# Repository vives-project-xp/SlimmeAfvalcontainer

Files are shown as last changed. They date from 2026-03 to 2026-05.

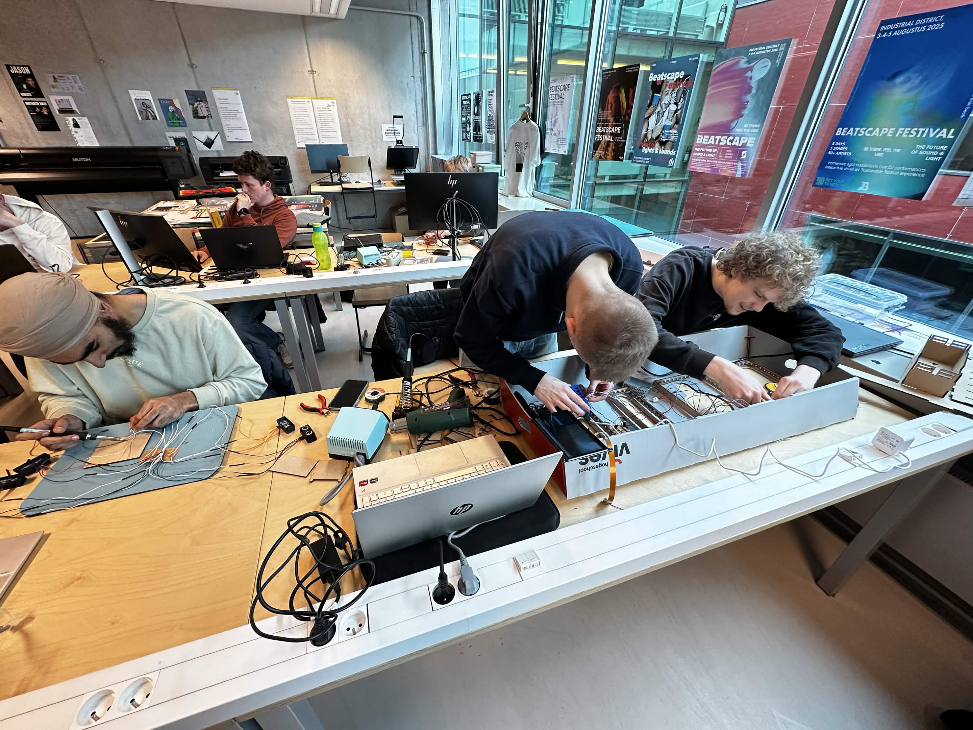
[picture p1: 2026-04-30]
SocialeMedia/Foto's/IMG_4296.jpg

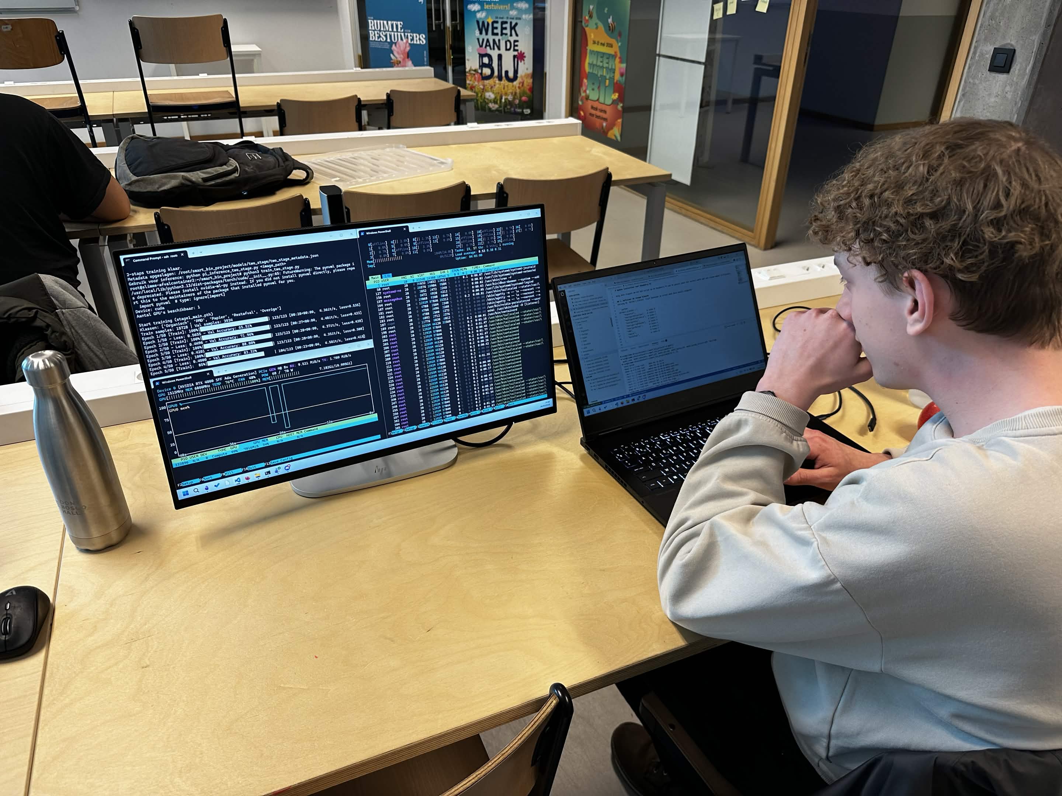
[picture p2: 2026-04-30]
SocialeMedia/Foto's/IMG_4295.jpg

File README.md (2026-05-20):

# Slimme Afvalcontainer

Een intelligente afvalcontainer met camera-gebaseerde objectdetectie, LED-indicatie en ultrasoon sensordetectie. 

## Inhoudstafel

| Onderdeel | Korte uitleg |
|---|---|
| [`Architectuur/`](Architectuur/) | Schema's en architectuurdocumenten van de oplossing. |
| [`Behuizingen/`](Behuizingen/) | Bestanden en ontwerpen voor de fysieke behuizing. |
| [`Code PI/`](Code%20PI/) | Hoofdcode voor de Raspberry Pi, inclusief GUI, LED-sturing en ultrasoon sensoren. |
| [`Datasets/`](Datasets/) | Informatie en links naar de datasets en model-artifacts op Kaggle. |
| [`Documentaties/`](Documentaties/) | Extra documentatie voor de Raspberry Pi en serveromgeving. |
| [`Pi_deploy_target96/`](Pi_deploy_target96/) | Deploy-bestanden voor het target96-model op de Raspberry Pi. |
| [`SocialeMedia/Poster/`](SocialeMedia/Poster/) | Poster- en presentatiemateriaal van het project. |
| [`RaspberryPI5_Pinout/`](RaspberryPI5_Pinout/) | Pinout-informatie voor de Raspberry Pi 5. |
| [`TestCodeC++/`](TestCodeC++/) | Testcode in C++ voor onderdelen van het systeem. |
| [`inference_gui.service`](inference_gui.service) | Systemd-service om de inferentie-GUI automatisch te starten. |
| [`start_garbage_gui.sh`](start_garbage_gui.sh) | Startscript voor de garbage detection GUI. |
| [`test_uart.py`](test_uart.py) | Python-testscript voor UART-communicatie. |

## Projectbeschrijving

Dit project implementeert een slimme afvalcontainer die:

- **Automatisch afvaltype detecteert** via camera en AI-objectdetectie.
- **Visueel aanduidt** welke container gebruikt moet worden met NeoPixel LED's.
- **Controleert of afval gevallen is** met ultrasoon sensoren.
- **Versnelde inferentie** ondersteunt via de Hailo AI Hat+.

## Hardware

| Component | Doel |
|---|---|
| Raspberry Pi 5 | Hoofd verwerkingseenheid |
| Hailo AI Hat+ | Hardware AI-acceleratie (optioneel) |
| Raspberry Pi Camera 3 | Objectdetectie |
| NeoPixel LED-strip | Visuele container-indicatie |
| Ultrasoon sensoren (HC-SR04) | Afvalniveaudetectie |

## GitHub en Kaggle verdeling

Deze repository bevat vooral:

- code
- documentatie
- configuratiebestanden
- het compacte referentie-modelpakket

Voor reproduceerbaarheid gebruiken we daarnaast Kaggle voor de grote bestanden:

- originele foto's: [Smart Bin Original Images](https://www.kaggle.com/datasets/maartenaudenaert/smart-bin-original-images)
- crops voor het finale model: [Smart Bin Classifier Crops](https://www.kaggle.com/datasets/maartenaudenaert/smart-bin-classifier-crops)
- zware modelbestanden en trainingsoutputs: [Smart Bin Model Artifacts](https://www.kaggle.com/datasets/maartenaudenaert/smart-bin-model-artifacts)

Met deze repo samen met die drie Kaggle-links kan het servergedeelte opnieuw worden opgebouwd.

## Gebruikte foto's en datastroom

De foto's zijn verzameld via:

- Google Dataset Search
- Kaggle
- [images.cv](https://images.cv/)

Een deel van de beelden kwam uit Amerikaanse datasets. Daardoor moesten we zelf foto's controleren en hersorteren, vooral voor `PMD`, zodat de sorteerlogica klopt met de regels in Brugge.

De flow voor het finale model is:

1. originele foto's
2. YOLO-detector zoekt het afvalobject
3. daaruit worden crops gemaakt
4. de two-stage classifier traint op die crops

## Serverdocumentatie

Voor de trainings- en exportflow:

- [Documentaties/Server/README.md](Documentaties/Server/README.md)
- [Documentaties/Server/Handleiding/README.md](Documentaties/Server/Handleiding/README.md)

## Links

- [Smart Bin Original Images](https://www.kaggle.com/datasets/maartenaudenaert/smart-bin-original-images)
- [Smart Bin Classifier Crops](https://www.kaggle.com/datasets/maartenaudenaert/smart-bin-classifier-crops)
- [Smart Bin Model Artifacts](https://www.kaggle.com/datasets/maartenaudenaert/smart-bin-model-artifacts)
- [Raspberry Pi Documentatie](https://www.raspberrypi.com/documentation/)
- [Pi Camera 3 Documentatie](https://www.raspberrypi.com/documentation/accessories/camera.html)
- [Hailo RPi5 Voorbeelden](https://github.com/hailo-ai/hailo-rpi5-examples)
- [NeoPixel LED Guide](https://learn.adafruit.com/adafruit-neopixel-uberguide)

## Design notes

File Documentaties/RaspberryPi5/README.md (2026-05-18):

# Smart Bin Raspberry Pi 5 documentatie

Deze map bevat de documentatie om het Raspberry Pi-gedeelte van de slimme
afvalcontainer te begrijpen, opnieuw klaar te zetten en te controleren.

Het gaat hier over de runtime op de Pi: GUI, camera, modelpakket, LED-strips,
ultrasone sensoren en autostart. Training en export van de modellen staan in:

[../Server](../Server/README.md)

## Inhoud

```text
RaspberryPi5/
|-- README.md
|-- Handleiding/
|   |-- README.md
|   |-- 01_pi_en_projectmap/
|   |-- 02_dependencies/
|   |-- 03_modelpakket/
|   |-- 04_gui_en_autostart/
|   |-- 05_leds_en_ultrasoon/
|   `-- 06_controle_en_troubleshooting/
`-- Bestanden/
    |-- README.md
    `-- MANIFEST.txt
```

## Waarvoor dient deze map?

- [Handleiding/](Handleiding/README.md) legt stap voor stap uit hoe de Pi wordt
  klaargezet en hoe de GUI automatisch start.
- [Bestanden/](Bestanden/README.md) beschrijft welke bestanden uit de repo en
  het modelpakket op de Pi nodig zijn.
- [Handleiding/05_leds_en_ultrasoon/hardware/](Handleiding/05_leds_en_ultrasoon/hardware/)
  bevat de detaildocumentatie voor LED-strips, ultrasone sensoren en bedrading.
- [Handleiding/03_modelpakket/referentie/deploy_gids_2_stage.md](Handleiding/03_modelpakket/referentie/deploy_gids_2_stage.md)
  bewaart de oorspronkelijke korte deploygids voor het two-stage model.

## Huidige referentie-installatie op de Pi

De actuele Pi gebruikt deze projectmap:

```text
/home/kobe/SlimmeAfvalcontainer
```

De GUI-service start via:

```text
/etc/systemd/system/garbagedetection-gui.service
```

Die service voert dit script uit:

```text
/home/kobe/SlimmeAfvalcontainer/start_garbage_gui.sh
```

Het huidige modelpakket staat op de Pi onder:

```text
/home/kobe/SlimmeAfvalcontainer/finalmodel
```

Voor compatibiliteit bestaat er ook een symlink:

```text
/home/kobe/SlimmeAfvalcontainer/test11mei_light_crops -> finalmodel
```

Die symlink is belangrijk zolang bestaande startbestanden nog naar
`test11mei_light_crops` verwijzen.

## Snel starten

1. Lees [Handleiding/README.md](Handleiding/README.md).
2. Begin met [01_pi_en_projectmap](Handleiding/01_pi_en_projectmap/README.md).
3. Installeer dependencies via [02_dependencies](Handleiding/02_dependencies/README.md).
4. Plaats of controleer het modelpakket via [03_modelpakket](Handleiding/03_modelpakket/README.md).
5. Zet autostart klaar via [04_gui_en_autostart](Handleiding/04_gui_en_autostart/README.md).
6. Controleer LEDs en ultrasoon via [05_leds_en_ultrasoon](Handleiding/05_leds_en_ultrasoon/README.md).
7. Gebruik [06_controle_en_troubleshooting](Handleiding/06_controle_en_troubleshooting/README.md) bij problemen.

## Belangrijkste runtimebestanden

- `garbagedetection_gui.py`: hoofd-GUI met camera, detectie, classificatie en UI.
- `detector.py`: YOLO ONNX-detectie.
- `classifier.py`: two-stage ONNX-classificatie.
- `led_controller.py`: aansturing van de vier WS2812B LED-strips.
- `ultrasone_controller.py`: monitoring van de vier ultrasone sensoren.
- `start_garbage_gui.sh`: startshellscript voor systemd.
- `garbagedetection-gui.service`: systemd-service voor automatische start.

## Belangrijk gedrag

De Pi gebruikt een detector + classifier-flow:

1. YOLO ONNX zoekt een object in het camerabeeld.
2. De beste crop wordt door de two-stage classifier gestuurd.
3. Stage 1 kiest de hoofdklasse.
4. Bij `Overige` draait Stage 2 voor de subklasse.
5. De GUI vertaalt het resultaat naar een bak of reject-status.
6. LEDs tonen de gekozen bak of een rood reject-signaal.
7. Ultrasone sensoren bevestigen inworp en tonen vulgraad.

## GitHub-opmerking

Niet pushen zonder eerst te controleren welke grote modelbestanden in Git horen.
Voor training en zware artifacts wordt dezelfde verdeling gevolgd als in de
serverdocumentatie:

- GitHub voor code, documentatie, scripts en compacte referentiebestanden
- externe opslag voor zware datasets en grote trainingsoutputs

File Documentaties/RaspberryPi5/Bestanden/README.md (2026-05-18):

# Bestanden Raspberry Pi 5

Deze map beschrijft welke bestanden nodig zijn op de Raspberry Pi. De echte
runtimebestanden staan in de repo vooral onder:

```text
Code PI/
```

en op de Pi onder:

```text
/home/kobe/SlimmeAfvalcontainer/finalmodel
/home/kobe/SlimmeAfvalcontainer/Code PI
```

## Belangrijkste bestanden uit de repo

| Bestand | Doel |
|---|---|
| `Code PI/garbagedetection_gui.py` | Hoofd-GUI |
| `Code PI/led_controller.py` | LED-aansturing |
| `Code PI/ultrasone_controller.py` | Ultrasone sensoren |
| `Code PI/garbagedetection-gui.service` | systemd-servicevoorbeeld |
| `start_garbage_gui.sh` | startshellscript |
| `inference_gui.service` | ouder/alternatief servicebestand |

## Belangrijkste bestanden in het modelpakket

| Bestand | Doel |
|---|---|
| `yolov8_detector.onnx` | YOLO-detector voor objectdetectie |
| `stage1_main.onnx` | Stage 1 hoofdklasse-classifier |
| `stage1_main.onnx.data` | externe data voor Stage 1 ONNX |
| `stage2_overige.onnx` | Stage 2 classifier voor Overige |
| `stage2_overige.onnx.data` | externe data voor Stage 2 ONNX |
| `two_stage_metadata.json` | labels, modelnamen en metadata |
| `detector.py` | ONNX detector wrapper |
| `classifier.py` | ONNX/two-stage classifier wrapper |
| `garbagedetection_gui.py` | runtime GUI in het pakket |

## Opmerking over dubbele LED-controller

De GUI draait uit `finalmodel`, maar de LED-subprocess-code kan
`led_controller.py` uit `Code PI` importeren. Daarom moeten wijzigingen aan
LED-gedrag in beide bestanden gecontroleerd worden:

```text
/home/kobe/SlimmeAfvalcontainer/finalmodel/led_controller.py
/home/kobe/SlimmeAfvalcontainer/Code PI/led_controller.py
```

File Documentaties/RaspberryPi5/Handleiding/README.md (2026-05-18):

# Handleiding Raspberry Pi 5 vanaf nul

Deze handleiding is opgesplitst per onderdeel. Ze is bedoeld voor iemand die de
Raspberry Pi 5-runtime van de slimme afvalcontainer opnieuw wil installeren of
controleren.

Training gebeurt niet op de Pi. De modellen worden serverkant getraind en daarna
als modelpakket naar de Pi gekopieerd.

## Volgorde

1. [Pi en projectmap klaarzetten](01_pi_en_projectmap/README.md)
2. [Dependencies installeren](02_dependencies/README.md)
3. [Modelpakket plaatsen](03_modelpakket/README.md)
4. [GUI en autostart instellen](04_gui_en_autostart/README.md)
5. [LEDs en ultrasoon controleren](05_leds_en_ultrasoon/README.md)
6. [Controle en troubleshooting](06_controle_en_troubleshooting/README.md)

## Detaildocumentatie

- [Two-stage deploygids referentie](03_modelpakket/referentie/deploy_gids_2_stage.md)
- [Hardwaredetails LEDs en ultrasoon](05_leds_en_ultrasoon/hardware/README.md)

## Wat draait er uiteindelijk?

Het doel is een automatisch startende GUI:

```text
garbagedetection-gui.service
`-- start_garbage_gui.sh
    `-- garbagedetection_gui.py --fullscreen
```

De GUI gebruikt dit modelpakket:

```text
finalmodel/
|-- yolov8_detector.onnx
|-- stage1_main.onnx
|-- stage1_main.onnx.data
|-- stage2_overige.onnx
|-- stage2_overige.onnx.data
|-- two_stage_metadata.json
|-- classifier.py
|-- detector.py
|-- led_controller.py
|-- ultrasone_controller.py
`-- garbagedetection_gui.py
```

## Belangrijke uitgangspunten

- De Pi draait de GUI, camera, LEDs en sensoren.
- De Pi traint geen modellen.
- Het modelpakket komt uit de serverflow.
- De huidige productieflow gebruikt `finalmodel`.
- De symlink `test11mei_light_crops -> finalmodel` houdt oude startpaden werkend.

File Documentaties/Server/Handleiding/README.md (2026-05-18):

# Handleiding vanaf nul

Deze handleiding is opgesplitst per onderdeel. Ze is bedoeld voor iemand die nog
geen VM, projectmap of trainingsomgeving heeft en het smart-bin trainingsresultaat
vanaf nul wil kunnen reproduceren.

## Volgorde

1. [VM en projectmap maken](01_vm_en_project/README.md)
2. [Dependencies installeren](02_dependencies/README.md)
3. [Dataset voorbereiden](03_dataset/README.md)
4. [YOLO-detector trainen of klaarzetten](04_detector/README.md)
5. [Cropdataset en two-stage classifier trainen](05_crop_classifier/README.md)
6. [Exporteren en modelpakket maken](06_export_modelpakket/README.md)
7. [Controle, GitHub en grote bestanden](07_controle_en_github/README.md)

## Wat wordt er uiteindelijk gemaakt?

Het doel is een map zoals:

```text
finalmodel/
|-- best.pt
|-- yolov8_detector.onnx
|-- stage1_main.onnx
|-- stage1_main.onnx.data
|-- stage2_overige.onnx
|-- stage2_overige.onnx.data
|-- two_stage_metadata.json
|-- classifier.py
|-- detector.py
|-- main.py
`-- pi_inference_two_stage.py
```

Een referentieversie van dat pakket staat in:

[../Bestanden/Huidig_modelpakket_finalmodel](../Bestanden/Huidig_modelpakket_finalmodel/)

## Belangrijke bijhorende bestanden

- [train_two_stage_crops.py](../Bestanden/Scripts_en_config/train_two_stage_crops.py)
- [export_two_stage_onnx.py](../Bestanden/Scripts_en_config/export_two_stage_onnx.py)
- [train_yolo_l.py](../Bestanden/Scripts_en_config/train_yolo_l.py)
- [train_yolo_until_target.py](../Bestanden/Scripts_en_config/train_yolo_until_target.py)
- [requirements.txt](../Bestanden/Scripts_en_config/requirements.txt)
- [two_stage_metadata.json](../Bestanden/Huidig_modelpakket_finalmodel/two_stage_metadata.json)

## Belangrijk uitgangspunt

Deze documentatie beschrijft serverkant training en export. De installatie op de
Raspberry Pi zelf hoort hier niet bij. De modelbestanden die later naar de Pi
gaan, worden hier wel gemaakt en verzameld.

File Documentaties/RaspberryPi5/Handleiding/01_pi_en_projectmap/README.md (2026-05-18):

# 1. Pi en projectmap klaarzetten

Dit onderdeel begint vanaf een Raspberry Pi 5 waarop Raspberry Pi OS al
geinstalleerd is.

## 1.1 Benodigdheden

Aanbevolen hardware:

```text
Raspberry Pi 5
Raspberry Pi Camera Module
Touchscreen of HDMI-scherm
4 WS2812B LED-strips
4 HC-SR04 ultrasone sensoren
5V voeding voor de LED-strips
netwerktoegang via Wi-Fi of ethernet
```

## 1.2 SSH-toegang

Voor de huidige Pi:

```bash
ssh kobe@10.10.226.229
```

Wachtwoord in de huidige testopstelling:

```text
kobe
```

Gebruik bij een andere Pi het juiste IP-adres.

## 1.3 Projectmap

De huidige projectmap op de Pi is:

```text
/home/kobe/SlimmeAfvalcontainer
```

Controle:

```bash
ls -la /home/kobe/SlimmeAfvalcontainer
```

Je moet onder andere deze onderdelen verwachten:

```text
Code PI/
finalmodel/
start_garbage_gui.sh
```

## 1.4 Modelmap en compatibele symlink

De huidige runtime gebruikt:

```text
/home/kobe/SlimmeAfvalcontainer/finalmodel
```

Omdat oude startbestanden vroeger naar `test11mei_light_crops` verwezen, bestaat
er een symlink:

```bash
cd /home/kobe/SlimmeAfvalcontainer
ln -s finalmodel test11mei_light_crops
```

Controle:

```bash
ls -ld /home/kobe/SlimmeAfvalcontainer/test11mei_light_crops
```

Verwachte output:

```text
test11mei_light_crops -> finalmodel
```

Zonder deze symlink kan de service falen als het startshellscript nog het oude
pad gebruikt.

## 1.5 Camera controleren

Controleer of de camera zichtbaar is:

```bash
rpicam-hello --list-cameras
```

Of test kort:

```bash
rpicam-hello -t 3000
```

Als dit niet werkt, moet eerst de camera-configuratie opgelost worden.

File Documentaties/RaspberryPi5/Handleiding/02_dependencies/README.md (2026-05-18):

# 2. Dependencies installeren

De Pi heeft Python-dependencies nodig voor camera, GUI, ONNX-inference, LEDs en
GPIO.

## 2.1 Systeempackages

Installeer basispackages:

```bash
sudo apt update
sudo apt install -y python3 python3-venv python3-pip python3-tk git
```

Voor camera en GPIO zijn op Raspberry Pi OS meestal al veel packages aanwezig.
Controleer indien nodig:

```bash
sudo apt install -y python3-picamera2 python3-rpi.gpio
```

## 2.2 Virtual environment

In de huidige installatie wordt deze venv gebruikt:

```text
/home/kobe/SlimmeAfvalcontainer/venv_ssp
```

Aanmaken:

```bash
cd /home/kobe/SlimmeAfvalcontainer
python3 -m venv venv_ssp
source venv_ssp/bin/activate
```

## 2.3 Pythonpackages

Installeer minimaal:

```bash
pip install --upgrade pip
pip install numpy pillow opencv-python onnxruntime
pip install adafruit-circuitpython-neopixel rpi_ws281x RPi.GPIO
```

Als `opencv-python` problemen geeft op de Pi, gebruik dan de OS-package:

```bash
sudo apt install -y python3-opencv
```

## 2.4 Rechten voor LEDs

De NeoPixel-library heeft toegang tot GPIO/PWM nodig. Daarom draait de huidige
service als `root`.

Controleer de service:

```bash
systemctl cat garbagedetection-gui.service
```

Verwacht in de huidige setup:

```text
User=root
Group=root
```

## 2.5 ONNX Runtime controleren

Test in de venv:

```bash
source /home/kobe/SlimmeAfvalcontainer/venv_ssp/bin/activate
python -c "import onnxruntime as ort; print(ort.__version__)"
```

Als dit faalt, kan de GUI de modellen niet laden.

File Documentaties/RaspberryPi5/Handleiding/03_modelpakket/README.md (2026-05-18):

# 3. Modelpakket plaatsen

Het modelpakket komt uit de serverdocumentatie. De Pi gebruikt het pakket alleen
voor inference.

De oorspronkelijke korte deploygids staat nu als referentie hier:

[referentie/deploy_gids_2_stage.md](referentie/deploy_gids_2_stage.md)

## 3.1 Huidige locatie

Op de huidige Pi:

```text
/home/kobe/SlimmeAfvalcontainer/finalmodel
```

Controle:

```bash
ls -lah /home/kobe/SlimmeAfvalcontainer/finalmodel
```

## 3.2 Vereiste modelbestanden

Minimaal nodig:

```text
yolov8_detector.onnx
stage1_main.onnx
stage1_main.onnx.data
stage2_overige.onnx
stage2_overige.onnx.data
two_stage_metadata.json
```

Belangrijke Pythonbestanden:

```text
garbagedetection_gui.py
detector.py
classifier.py
led_controller.py
ultrasone_controller.py
```

## 3.3 Inference-flow

De runtime werkt in twee delen:

1. `yolov8_detector.onnx` zoekt objecten in het camerabeeld.
2. De beste crop wordt door de two-stage classifier gestuurd.

Two-stage classifier:

1. Stage 1 kiest een hoofdklasse:

```text
Organisch
PMD
Papier
Restafval
Overige
```

2. Alleen bij `Overige` draait Stage 2:

```text
Batterijen
Elektronica
Glas
Lightbulbs
Metaal
```

3. De GUI combineert dit als bijvoorbeeld:

```text
Overige/Batterijen
```

## 3.4 Metadata

Labels en thresholds mogen niet hardcoded worden als ze uit metadata kunnen
komen. Controleer:

```bash
cat /home/kobe/SlimmeAfvalcontainer/finalmodel/two_stage_metadata.json
```

Belangrijke velden:

```text
input_size
stage1_classes
stage2_overige_classes
stage1_model
stage2_model
main_label_for_stage2
default_fallback
```

## 3.5 Foto-opslag

De huidige runtime mag geen capturefoto's opslaan.

Controleer dat deze map niet terugkomt:

```bash
find /home/kobe/SlimmeAfvalcontainer/finalmodel -maxdepth 1 -type d -name captures
```

Controleer ook dat de GUI geen save-call meer uitvoert:

```bash
grep -n "_save_capture_photo(pil_img)" /home/kobe/SlimmeAfvalcontainer/finalmodel/garbagedetection_gui.py
```

Er hoort geen resultaat terug te komen.

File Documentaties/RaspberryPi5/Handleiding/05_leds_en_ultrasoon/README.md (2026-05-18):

# 5. LEDs en ultrasoon controleren

De Pi gebruikt LED-strips om de gekozen bak te tonen en ultrasone sensoren om
vulgraad en inworp te detecteren.

## 5.1 LED-pinnen

GPIO-mapping volgens de huidige `led_controller.py`:

| Bak | GPIO | Standaardkleur |
|---|---:|---|
| Restafval | GPIO18 | rood |
| Karton/Papier | GPIO13 | blauw |
| Organisch | GPIO12 | groen |
| PMD | GPIO19 | geel |

Detaildocumentatie:

- [hardware/README.md](hardware/README.md)
- [hardware/ledstrip.md](hardware/ledstrip.md)
- [hardware/bedrading.md](hardware/bedrading.md)

## 5.2 LED-gedrag bij classificatie

De GUI vertaalt labels naar een bak of reject-status.

| Modelresultaat | LED-gedrag |
|---|---|
| `Organisch` | Organisch groen, andere bakken rood |
| `PMD` | PMD groen, andere bakken rood |
| `Papier` | Karton/Papier groen, andere bakken rood |
| `Restafval` | Restafval groen, andere bakken rood |
| `Overige` | alle LEDs rood knipperen en rood blijven |
| `Overige/<subklasse>` | alle LEDs rood knipperen en rood blijven |

De subklassen gaan dus bewust naar geen enkele bak:

```text
Overige/Batterijen
Overige/Elektronica
Overige/Glas
Overige/Lightbulbs
Overige/Metaal
```

## 5.3 Waarom rood bij Overige?

`Overige` en alle subklassen betekenen dat de afvalcontainer geen veilige
standaardbak mag kiezen. De LEDs geven daarom een reject-signaal:

```text
reject_blink
```

Dat commando start het knipperen in een subproces, zodat de camera en GUI niet
blijven wachten tot de LED-animatie klaar is.

## 5.4 Oranje flash

Oranje betekent:

```text
inworp bevestigd
```

De ultrasone sensor heeft dan gedetecteerd dat er effectief iets in de gekozen
bak gegooid werd.

Bij `Overige` hoort er normaal geen bak gekozen te worden en dus ook geen
inworp-confirmatie voor een specifieke bak.

## 5.5 Ultrasone pinnen

GPIO-mapping volgens de huidige documentatie:

| Bak | TRIG | ECHO |
|---|---:|---:|
| Restafval | GPIO25 | GPIO26 |
| PMD | GPIO22 | GPIO4 |
| Papier | GPIO23 | GPIO24 |
| Organisch | GPIO17 | GPIO27 |

Detaildocumentatie:

- [hardware/README.md](hardware/README.md)
- [hardware/ultrasone.md](hardware/ultrasone.md)
- [hardware/bedrading.md](hardware/bedrading.md)

## 5.6 Snelle LED-test

Op de Pi:

```bash
cd /home/kobe/SlimmeAfvalcontainer/finalmodel
sudo LED_PROCESS_ISOLATION=0 /home/kobe/SlimmeAfvalcontainer/venv_ssp/bin/python -c "from led_controller import LedController; c=LedController(); print(c.send_command('select_pmd'))"
```

Alles uit:

```bash
sudo LED_PROCESS_ISOLATION=0 /home/kobe/SlimmeAfvalcontainer/venv_ssp/bin/python -c "from led_controller import LedController; c=LedController(); print(c.send_command('off'))"
```

Reject-test:

```bash
sudo LED_PROCESS_ISOLATION=0 /home/kobe/SlimmeAfvalcontainer/venv_ssp/bin/python -c "from led_controller import LedController; c=LedController(); print(c.send_command('reject_blink'))"
```

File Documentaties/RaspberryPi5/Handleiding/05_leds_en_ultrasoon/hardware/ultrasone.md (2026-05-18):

# Ultrasone sensor documentatie

## Overzicht

`ultrasone_controller.py` bewaakt de vullingsgraad van 4 afvalbakken via HC-SR04 ultrasonische sensoren. De metingen lopen continu in een **achtergrond-thread**. Andere modules (bv. `inference_gui.py`) halen de meest recente status op via de `snapshot()` methode.

---

## Hardware

### Sensoren

Elke bak heeft één HC-SR04 sensor met een **TRIG**-pin (trigger) en een **ECHO**-pin. De sensor is diagonaal in de bakhoek geplaatst; de kalibratie-afstand voor een lege bak is daarom langer dan de verticale bakhoogte.

### GPIO pin-mapping (BCM)

| Bak | TRIG pin | ECHO pin |
|---|---|---|
| `rest` | GPIO 25  | GPIO 26  |
| `pmd` | GPIO 22  | GPIO 4 |
| `papier`  | GPIO 16  | GPIO 24  |
| `org` | GPIO 17  | GPIO 27  |

> De GPIO-nummering volgt het BCM-schema (niet de fysieke pin-nummers).

### Aansluitschema per sensor

De HC-SR04 werkt op 5V en geeft een 5V ECHO-signaal terug. De Raspberry Pi GPIO-pinnen zijn echter **3,3V-logica**. Om de GPIO te beschermen wordt een **spanningsdeler** gebruikt op de ECHO-lijn.

**Spanningsdeler (ECHO):**

```
HC-SR04 ECHO (5V)
        │
      [1kΩ]
        │
        ├──── GPIO-pin (Raspberry Pi)
        │
      [2kΩ]
        │
       GND
```

Uitgangsspanning: `5V × 2kΩ / (1kΩ + 2kΩ) ≈ 3,33V` — veilig voor de Raspberry Pi GPIO.

De TRIG-lijn heeft **geen** spanningsdeler nodig: de Pi stuurt 3,3V uit en de HC-SR04 accepteert dit als geldig HIGH-signaal.

**Volledig schema per sensor:**

```
Raspberry Pi GPIO          HC-SR04
  TRIG-pin ─────────────── TRIG
  ECHO-pin ──[1kΩ]──┬───── ECHO
                  [2kΩ]
                    │
                   GND
  GND      ─────────────── GND
  5V       ─────────────── VCC
```

---

## Installatie & vereisten

```bash
pip install RPi.GPIO
```

De module vereist toegang tot GPIO-hardware. Draai het script als root of via `sudo` als GPIO-permissies dit vereisen.

---

## Configuratie

De drempelwaarden zijn klasseconstanten in `UltrasonicMonitor`:

| Constante | Standaard | Beschrijving |
|---|---|---|
| `EMPTY_DISTANCE_CM` | `75.0` | Gekalibreerde afstand (cm) bij een volledig lege bak |
| `THROW_THRESHOLD_CM` | `10.0` | Minimale afstandsdaling (cm) om een inworp te registreren |
| `THROW_DEBOUNCE_S` | `1.5` | Minimale tijd (s) tussen twee opeenvolgende inworp-detecties |
| `THROW_CONFIRM_DELAY_S` | `0.8` | Wachttijd (s) vóór bevestigingsmeting na een mogelijke inworp |
| `THROW_CONFIRM_SAMPLES` | `5` | Aantal samples voor de bevestigingsmeting |
| `THROW_STATUS_HOLD_S` | `2.0` | Hoe lang (s) de status "inworp gedetecteerd" zichtbaar blijft |

---

## Vullingsgraad berekening

De fill-percentage wordt berekend op basis van de gemeten afstand ten opzichte van de lege-bak-referentie:

**Formule:**
```
fill_pct = ((EMPTY_DISTANCE_CM - gemeten_cm) / EMPTY_DISTANCE_CM) * 100
```

Geldige meetafstand: tussen **2 cm** en **400 cm**. Buiten dit bereik geldt de meting als ongeldig (`None`).

Een bak wordt als **vol** beschouwd als:
- gemeten afstand < 5 cm, **of**
- `fill_pct >= 95`

---

## Inworp-detectie

De controller detecteert een inworp via een twee-staps confirmatieprocedure om valse positieven te vermijden:

1. **Drempelcheck**: de afstand daalt meer dan `THROW_THRESHOLD_CM` ten opzichte van de vorige meting.
2. **Debounce**: er zijn minstens `THROW_DEBOUNCE_S` seconden verstreken sinds de laatste inworp.
3. **Bevestiging**: na `THROW_CONFIRM_DELAY_S` seconden wordt opnieuw gemeten (`THROW_CONFIRM_SAMPLES` samples). De daling moet nog steeds aanwezig zijn.
4. **Resultaat**: bij bevestiging wordt `threw_object = True` en wordt de tijdstempel bijgewerkt.

---

## API-referentie

### `UltrasonicMonitor(debug=False, debug_every_cycles=1, sensor_overrides=None)`

Start de achtergrond-thread en initialiseert de GPIO-pinnen.

| Parameter | Type | Beschrijving |
|---|---|---|
| `debug` | `bool` | Zet debug-uitvoer aan in de terminal |
| `debug_every_cycles` | `int` | Druk debug-info elke N meetcycli af (standaard elke cyclus) |
| `sensor_overrides` | `dict[str, dict[str, int] \| None] \| None` | Overschrijf de TRIG/ECHO-pinnen per bak; geef `None` om een bak uit te schakelen |

Bij een mislukte GPIO-initialisatie blijft het object actief maar worden metingen overgeslagen (`enabled = False`).

**Voorbeeld met pin-override:**
```python
monitor = UltrasonicMonitor(
    sensor_overrides={"org": {"trig": 6, "echo": 5}}
)
```

**Voorbeeld met bak uitschakelen:**
```python
monitor = UltrasonicMonitor(
    sensor_overrides={"org": None}
)
```

---

### `snapshot() -> dict[str, dict[str, object]]`

Geeft een momentopname van de huidige sensorstatus terug. Thread-safe.

**Returnstructuur:**
```python
{
    "rest": {
        "fill_pct": int | None,  # Vulgraad 0–100, of None bij geen meting
        "is_full":  bool,        # True als bak vol is
        "threw_object": bool,    # True bij vers gedetecteerde inworp
        "text": str,             # Leesbare statustekst
    },
    # ook "pmd", "papier", "org"
}
```

**Mogelijke statusteksten:**

| Toestand | `text` |
|---|---|
| Geen geldige meting | `"geen meting"` |
| Bak vol | `"VOL (97%)"` |
| Inworp zojuist gedetecteerd | `"inworp gedetecteerd (42%)"` |
| Bak bijna vol (≥ 80 %) | `"bijna vol (83%)"` |
| Normale toestand | `"45%"` |
| Sensor uitgeschakeld of niet aanwezig | `"n.v.t."` |
| Status nog onbekend (bij opstart) | `"onbekend"` |

---

### `close()`

Stopt de achtergrond-thread en maakt de GPIO-resources vrij via `GPIO.cleanup()`. Altijd aanroepen bij afsluiten.

---

## Debug-modus

Zet `debug=True` om per meetcyclus een samenvatting in de terminal te printen:

```
[Ultrasoon DEBUG] rest   trig=25 echo=26 distance=  38.4cm fill= 48 throw=False status=48%
[Ultrasoon DEBUG] pmd    trig=22 echo= 4 distance=  12.1cm fill= 83 throw=False status=bijna vol (83%)
[Ultrasoon DEBUG] papier trig=23 echo=24 distance=   4.2cm fill=100 throw=False status=VOL (100%)
[Ultrasoon DEBUG] org    trig=17 echo=27 distance=  None   fill= -1 throw=False status=geen meting
[Ultrasoon DEBUG] ------------------------------------------------------------------------
```

Met `debug_every_cycles=10` wordt de uitvoer slechts elke 10 cycli geprint.

---

## Gebruik als module

```python
from ultrasone_controller import UltrasonicMonitor

monitor = UltrasonicMonitor()

status = monitor.snapshot()
print(status["rest"]["fill_pct"])      # bv. 48
print(status["pmd"]["threw_object"])   # bv. True
print(status["papier"]["text"])        # bv. "bijna vol (83%)"

monitor.close()
```

---

## Klasse-diagram

```
UltrasonicMonitor
├── __init__(debug, debug_every_cycles, sensor_overrides)
│   ├── GPIO-pinnen instellen (TRIG/ECHO per bak)
│   └── achtergrond-thread starten
│
├── snapshot() -> dict
│   └── thread-safe kopie van _status teruggeven
│
├── Interne methodes
│   ├── _loop()                         – meetlus in achtergrond-thread
│   ├── _measure_distance(cfg)          – enkele HC-SR04 meting (cm of None)
│   ├── _measure_average(cfg, samples)  – gemiddelde van N metingen
│   ├── _calc_fill_pct(distance_cm)     – omrekenen naar vulpercentage
│   ├── _detect_throw_event(...)        – inworp-detectie met bevestiging
│   └── _debug_print(msg)               – conditionele terminal-uitvoer
│
└── close()
```

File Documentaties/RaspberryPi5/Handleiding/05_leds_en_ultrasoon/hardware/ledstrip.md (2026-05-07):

# LED-strip documentatie

## Overzicht

`led_controller.py` stuurt 4 WS2812B LED-strips aan via de GPIO-pinnen van de Raspberry Pi. Elke strip stelt één afvalcategorie voor en krijgt een eigen kleur. De controller biedt een eenvoudige `send_command(cmd)` API die door andere modules (bv. `inference_gui.py`) gebruikt wordt.

---

## Hardware

### Voeding

De strips worden gevoed door een **Meanwell RS-25-5** (5V, 5A). Per strip is een **1000 µF elektrolytische condensator** geplaatst tussen de voeding en de strip om inrushstroom bij het opstarten op te vangen en spanningspieken te dempen. Er zijn dus **4 condensators** in totaal.

**Aansluitschema per strip:**

```
Meanwell RS-25-5
  +5V ──┬─────────────────────────────── +5V ingang LED-strip
       (+)
    condensator
      1000µF
       (−)
        │
  GND ──┴─────────────────────────────── GND ingang LED-strip
```

De condensator hangt **parallel** over de voedingsrail: (+) naar +5V, (−) naar GND. Hij staat dus niet in serie in de stroomweg, maar filtert spanningspieken op de rail.

> Let op de polariteit: de positieve pool naar +5V, de negatieve pool naar GND.

### DIN-lijn weerstand

Op elke **DIN-lijn** (datasignaal van de Raspberry Pi naar de strip) zit een **220 Ω weerstand** in serie. Dit beschermt de eerste LED-driver tegen te hoge instroompieken en vermindert reflecties op de signaalleiding.

```
GPIO-pin ──[ 220 Ω ]──── DIN LED-strip
```

### GPIO pin-mapping (BCM)

| Strip naam | GPIO pin | Aantal LEDs |
|---|---|---|
| `rest` | GPIO 18  | 50 |
| `karton` | GPIO 13  | 37 |
| `organisch`  | GPIO 12  | 50 |
| `pmd` | GPIO 19  | 51 |

> De GPIO-nummering volgt het BCM-schema (niet de fysieke pin-nummers).

### Kleurcodering per afvalcategorie

| Categorie | Kleur | RGB-waarde |
|---|---|---|
| `rest` | Rood | (255, 70, 70) |
| `karton` | Blauw | (70, 140, 255)  |
| `organisch`  | Groen | (0, 255, 0) |
| `pmd` | Geel | (255, 190, 40)  |

### Speciale kleuren

| Toestand | Kleur | RGB-waarde |
|---|---|---|
| Correct (groen) | Groen | (0, 255, 0) |
| Fout (rood) | Rood | (255, 0, 0) |
| Uit | Uit | (0, 0, 0) |

### Overige afvaltypes (speciale kleurenmap)

| Commando | Kleur | RGB-waarde |
|---|---|---|
| `overige` | Lichtgrijs | (160, 160, 160) |
| `overige_batterijen` | Oranje | (255, 120, 40) |
| `overige_elektronica` | Rood-oranje | (255, 60, 60) |
| `overige_glas` | Teal | (40, 190, 170) |
| `overige_lightbulbs` | Geel | (255, 230, 90) |
| `overige_metaal` | Bruin | (150, 120, 95) |

---

## Installatie & vereisten

```bash
pip install adafruit-circuitpython-neopixel rpi_ws281x
```

De neopixel-library vereist toegang tot de GPIO-hardware. Draai het script als root of via `sudo` als GPIO-permissies dit vereisen.

---

## Configuratie via omgevingsvariabelen

Alle instellingen hebben een standaardwaarde maar kunnen overschreven worden via omgevingsvariabelen:

| Variabele | Standaard | Beschrijving |
|---|---|---|
| `LED_BRIGHTNESS` | `0.25` | Helderheid van alle strips (0.0 – 1.0) |
| `LED_MAX_CURRENT_A` | `5.0` | Maximale stroomtoevoer in ampère |
| `LED_CURRENT_HEADROOM`  | `0.85` | Veiligheidsmarge op de max stroom (bijv. 85%) |
| `LED_COUNT_REST` | `50` | Aantal LEDs op de REST-strip |
| `LED_COUNT_KARTON` | `37` | Aantal LEDs op de KARTON-strip |
| `LED_COUNT_ORGANISCH` | `50` | Aantal LEDs op de ORGANISCH-strip |
| `LED_COUNT_PMD` | `51` | Aantal LEDs op de PMD-strip |
| `LED_PROCESS_ISOLATION` | `1` | Subproces-isolatie aan (`1`) of uit (`0`) |

Voorbeeld:
```bash
LED_BRIGHTNESS=0.5 LED_MAX_CURRENT_A=3.0 python led_controller.py
```

---

## Stroombeveiliging (current limiting)

De controller berekent voor elke strip de geschatte stroomopname op basis van de RGB-waarden. Als de totale geschatte stroom de limiet overschrijdt, worden de RGB-waarden proportioneel teruggeschaald.

**Formule:**
```
I_per_led = (R + G + B) / 255 * 20mA
I_totaal  = I_per_led * aantal_leds
```

Als `I_totaal > MAX_CURRENT * HEADROOM`, worden R, G en B vermenigvuldigd met de schaalfactor:
```
schaal = limiet / I_totaal
```

De controller logt dit in de terminal:
```
[LED] Current limit toegepast voor rest: (255, 70, 70) -> (180, 49, 49) (est 6.23A > 4.25A)
```

---

## Subproces-isolatie (process isolation)

Standaard (`LED_PROCESS_ISOLATION=1`) stuurt de controller elk commando door naar een **apart Python-subproces**. Dit beschermt de GUI tegen crashes die veroorzaakt worden door de native neopixel/GPIO-bibliotheek.

- Het kindproces initialiseert zijn eigen `LedController` met `LED_PROCESS_ISOLATION=0`
- Het resultaat wordt via `stdout` teruggegeven aan het hoofdproces
- Timeout per commando: 5 seconden

Zet isolatie uit voor hogere snelheid of bij directe hardware-integratie:
```bash
LED_PROCESS_ISOLATION=0 python led_controller.py
```

---

## API-referentie

### `LedController(led_count_map=None, brightness=0.25)`

Initialiseer de controller. Bij een mislukte GPIO-init blijft de controller actief maar worden LED-commando's genegeerd (de GUI crasht niet).

### `send_command(cmd: str) -> str`

Stuur een commando naar de strips. Geeft een statusstring terug.

#### Ondersteunde commando's

| Commando | Gedrag |
|---|---|
| `pmd` | Enkel de PMD-strip aan in geel, rest uit |
| `rest` | Enkel de REST-strip aan in rood, rest uit |
| `karton` / `papier` | Enkel de KARTON-strip aan in blauw, rest uit (`papier` is alias voor `karton`) |
| `organisch` / `bio` | Enkel de ORGANISCH-strip aan in groen, rest uit (`bio` is alias voor `organisch`) |
| `all` | Alle 4 strips aan in hun eigen kleur |
| `idle` | Zelfde als `all` — alle strips aan in hun eigen kleur |
| `select_<naam>` | Geselecteerde strip groen, de overige drie rood (visuele bevestiging juiste bak) |
| `reject` | Alle strips rood (ongekend of fout afval) |
| `hit` | Herhaal de laatst gekozen categorie (nuttig bij opeenvolgende detecties) |
| `off` | Alle strips uit |
| `reset` | Alle strips uit + reset huidige keuze naar `NONE` |
| `overige` | Alle strips in lichtgrijs |
| `overige_batterijen`  | Alle strips in oranje |
| `overige_elektronica` | Alle strips in rood-oranje |
| `overige_glas` | Alle strips in teal |
| `overige_lightbulbs`  | Alle strips in geel |
| `overige_metaal` | Alle strips in bruin |

#### Returnwaarden

| Return | Betekenis |
|---|---|
| `OK: <CMD>` | Commando succesvol uitgevoerd |
| `UNKNOWN: <cmd>`  | Onbekend commando |
| `ERROR: <cmd>` | Fout tijdens uitvoering |

### `close()`

Zet alle strips uit en geeft GPIO-resources vrij. Altijd aanroepen bij afsluiten.

---

## Gebruik als module

```python
from led_controller import LedController

ctrl = LedController()

ctrl.send_command("pmd")        # PMD-strip aan
ctrl.send_command("select_pmd") # PMD groen, rest rood
ctrl.send_command("all")        # Alle strips aan
ctrl.send_command("off")        # Alles uit

ctrl.close()
```

---

## Standalone testen

```bash
python "Code PI/led_controller.py"
```

Dit doorloopt automatisch de commando's `pmd → rest → karton → organisch → hit → off` met 2 seconden tussentijd.

---

## Klasse-diagram

```
LedController
├── __init__(led_count_map, brightness)
│   ├── proxy_mode: LED-IO via subprocess
│   └── direct: neopixel strips initialiseren
│
├── send_command(cmd) -> str
│   ├── _send_command_via_subprocess(cmd)  [proxy mode]
│   └── directe strip-aanturing            [direct mode]
│
├── Interne methodes
│   ├── _show_bin(bin_name)         – één strip aan, rest uit
│   ├── _show_all_bins()            – alle strips in eigen kleur
│   ├── _show_all_color(rgb)        – alle strips zelfde kleur
│   ├── _show_selection(bin_name)   – groen/rood feedback
│   ├── _set_all(rgb)               – alle strips zelfde kleur (laag niveau)
│   ├── _limit_color_for_strip()    – current limiting
│   └── _estimate_led_current_a()   – stroomschatting
│
└── close()
```

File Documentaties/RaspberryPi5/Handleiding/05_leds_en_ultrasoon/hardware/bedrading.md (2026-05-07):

# Bedrading en softwareconfig WS2812B (4 strips direct op Raspberry Pi)

Deze setup gebruikt geen ESP32 en geen UART meer.
De GUI stuurt de leds direct aan via [Code PI/led_controller.py](Code%20PI/led_controller.py).

## GPIO pinnen voor 4 aparte strips

- REST -> GPIO18 (fysieke pin 12)
- KARTON -> GPIO13 (fysieke pin 33)
- ORGANISCH -> GPIO12 (fysieke pin 32)
- PMD -> GPIO19 (fysieke pin 35)

Deze mapping komt exact overeen met de softwareconfig.

## Aansluiten per strip

Per strip heb je 3 verbindingen:

- 5V voeding -> 5V van de strip
- GND -> GND van de strip
- DATA van gekozen GPIO -> DIN van de strip

## Verplichte extra componenten voor WS2812B

- Plaats een serieweerstand van 330-470 ohm in de datalijn van elke strip.
- Plaats een elco van 1000 uF (minimaal 6.3V) tussen 5V en GND bij de start van de strips.
- Gebruik een externe 5V voeding voor de strips (niet alleen via Pi 5V pin bij veel leds).
- Verbind alle gronden met elkaar: Pi GND + voeding GND + alle strip GND.

## Spanningsniveau data (belangrijk)

De Raspberry Pi gebruikt 3.3V datalogica.
WS2812B op 5V werkt soms direct, maar voor stabiele werking is een level shifter sterk aanbevolen:

- 74AHCT125 of 74HCT14 (3.3V -> 5V) op elke datalijn.

## Voeding snelcheck

Rekenregel: maximaal ongeveer 60 mA per led bij vol wit op 100%.

Formule:

- I_max = aantal_leds * 0.06 A

Voorbeeld bij 191 leds totaal:

- 191 * 0.06 = 11.46 A (theoretisch maximum)

In de praktijk vaak lager door brightness-limiet, maar kies voeding met marge.

## Software vereisten (Pi)

Benodigde Python packages in je venv:

- adafruit-circuitpython-neopixel
- rpi_ws281x

En op OS-niveau:

- Python met GPIO toegang
- start de app bij voorkeur met sudo voor stabiele ws281x toegang

## Runtime configuratie

De led-controller ondersteunt deze omgevingsvariabelen:

- LED_COUNT_REST (standaard: 51)
- LED_COUNT_KARTON (standaard: 38)
- LED_COUNT_ORGANISCH (standaard: 51)
- LED_COUNT_PMD (standaard: 51)
- LED_BRIGHTNESS (standaard: 0.25)
- LED_MAX_CURRENT_A (standaard: 5.0)
- LED_CURRENT_HEADROOM (standaard: 0.85)

Voorbeeld:

- LED_COUNT_REST=51 LED_COUNT_KARTON=38 LED_COUNT_ORGANISCH=51 LED_COUNT_PMD=51 LED_BRIGHTNESS=0.20 LED_MAX_CURRENT_A=5.0 LED_CURRENT_HEADROOM=0.85 sudo -E /pad/naar/python [Code PI/inference_gui.py](Code%20PI/inference_gui.py)

Stroomlimiter in software:

- De controller schat stroom op basis van RGB-waarde en aantal leds van de actieve strip.
- Als de geschatte stroom boven de limiet komt, schaalt de software de RGB-waarde automatisch omlaag.
- Effectieve limiet = LED_MAX_CURRENT_A * LED_CURRENT_HEADROOM.

Huidige fysieke setup:

- REST: 51 leds
- KARTON: 38 leds
- ORGANISCH: 51 leds
- PMD: 51 leds

## Commando mapping vanuit GUI

De GUI stuurt commando's naar de controller:

- organisch -> ORGANISCH strip aan
- pmd -> PMD strip aan
- karton -> KARTON strip aan
- rest -> REST strip aan
- papier -> alias van karton
- bio -> alias van organisch
- off -> alle strips uit
- reset -> alle strips uit en keuze reset

Bij een nieuw commando gaat eerst alles uit, daarna alleen de gekozen strip aan.

## HC-SR04 ultrasonische sensors (4x)

Onderstaande pinout komt overeen met de originele `Ultrasone_controller.py`:

- Sensor 1 (Restafval): TRIG -> GPIO25 (pin 22), ECHO -> GPIO26 (pin 37)
- Sensor 2 (PMD): TRIG -> GPIO22 (pin 15), ECHO -> GPIO4 (pin 7)
- Sensor 3 (Papier): TRIG -> GPIO23 (pin 16), ECHO -> GPIO24 (pin 18)
- Sensor 4 (Glas): TRIG -> GPIO17 (pin 11), ECHO -> GPIO27 (pin 13)

Power voor alle HC-SR04:
- VCC -> 5V (pin 2 of 4)
- GND -> GND (bijv. pin 6, 9, 14, ...)

Belangrijk: ECHO is 5V output. Gebruik altijd een niveauadapter of een weerstandendeler naar 3.3V voor elke ECHO-lijn voordat je het op Pi GPIO input aansluit.

TRIG kan direct vanaf Pi 3.3V output (HC-SR04 erkent dit als hoog genoeg).

### Ultrasonische timing in Python

1. Zet TRIG output laag (2 ms)
2. Zet TRIG ~10 µs hoog
3. Zet TRIG laag
4. Meet hoelang ECHO hoog blijft
5. Afstand (cm) = (duration_microsec / 58)

### Cross-talk voorkomen

- Trigger sensoren één voor één (niet tegelijk), met kleine pauze tussen de metingen.
- Zorg dat je aansturing in software sequentieel gebeurt (sensor 1 -> 2 -> 3 -> 4) en niet parallel, anders kun je echo's verwisselen.

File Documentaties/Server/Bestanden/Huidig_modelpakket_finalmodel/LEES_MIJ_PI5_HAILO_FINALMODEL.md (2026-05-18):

# Test11mei Light Crops: Pi 5 + Hailo HAT pakket

Deze map is bedoeld als klaarzet-map voor de Raspberry Pi 5 met Hailo HAT.

Status:
- dit mapje is bedoeld voor de lichte detectorvariant voor Pi 5 + Hailo HAT
- de two-stage classifierbestanden zitten er al in
- die classifier is nu de crop-gebaseerde two-stage variant uit `models/two_stage_crops`
- de lichte detectorbestanden zitten er ook al in

Wat er nu al in zit:
- `classifier.py`
- `detector.py`
- `hailo_two_stage_main.py`
- `main.py`
- `pi_inference_two_stage.py`
- `stage1_main.onnx`
- `stage1_main.onnx.data`
- `stage2_overige.onnx`
- `stage2_overige.onnx.data`
- `two_stage_metadata.json`

Wat er nog ontbreekt voor Hailo:
- `yolov8_detector.hef`

## Verwachte detectorrun
Runmap:

```bash
/root/smart_bin_project/runs/yolo_light/garbage_detector_pi_light
```

## Stap 1: Controleer deze map
Deze bestanden zouden hier nu aanwezig moeten zijn:
- `best.pt`
- `yolov8_detector.onnx`
- `stage1_main.onnx`
- `stage2_overige.onnx`
- `two_stage_metadata.json`
- `hailo_two_stage_main.py`

## Stap 2: Detector opnieuw exporteren indien nodig
Als je later een nieuwere lichte detectorrun wilt inladen, voer je op de server uit:

```bash
cd /root/smart_bin_project/finalmodel
bash vul_detector_na_training.sh
```

Dat script doet:
- `best.pt` kopieren naar deze map
- `best.pt` exporteren naar ONNX
- de ONNX detector hernoemen naar `yolov8_detector.onnx`

Je kunt ook een andere runmap opgeven:

Standaard haalt dat script de detector uit:

```bash
/root/smart_bin_project/runs/yolo_light/garbage_detector_pi_light
```

## Stap 3: Kopieer deze map naar de Pi 5
Bijvoorbeeld:

```bash
scp -r /root/smart_bin_project/finalmodel pi@<IP_VAN_PI>:/home/pi/
```

## Stap 4: Detector klaarmaken voor Hailo
De Hailo runtime in `hailo_two_stage_main.py` verwacht een bestand met deze naam:

```bash
yolov8_detector.hef
```

Gebruik dus jullie normale Hailo compile-flow om van `best.pt` of `yolov8_detector.onnx` een `.hef` te maken en zet dat bestand in deze map met exact die naam.

Belangrijk:
- `main.py` gebruikt `yolov8_detector.onnx` voor CPU/ONNX-testen
- `hailo_two_stage_main.py` gebruikt `yolov8_detector.hef` voor de Hailo HAT

## Stap 5: Starten op de Pi
Voor Hailo HAT:

```bash
cd ~/finalmodel
python3 hailo_two_stage_main.py
```

Voor ONNX/CPU test:

```bash
cd ~/finalmodel
python3 main.py
```

## Stap 6: Snelle visuele controle
Na training kun je hier evaluatiebestanden verwachten in `evaluatie/`.

## Opmerking
De two-stage classifier in deze map is nu de crop-gebaseerde variant uit `models/two_stage_crops`:
- `stage1_main` validatie-accuracy: `89.46%`
- `stage2_overige` validatie-accuracy: `92.03%`

De detector kan later nog vervangen worden door een nieuwere `best.pt`/`yolov8_detector.onnx`/`.hef` zonder dat je de classifierbestanden opnieuw hoeft te maken.

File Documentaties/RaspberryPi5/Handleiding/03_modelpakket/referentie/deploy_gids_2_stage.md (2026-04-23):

# Raspberry Pi 5 Deploy Gids (2-Stage Model)

Deze gids start **na training**.  
Training is al klaar; we focussen alleen op wat nodig is om inference op de Pi 5 te laten werken.

modellen staan in: 
/home/kobe/SlimmeAfvalcontainer/Code PI/AI

`/home/pi/smart_bin/models/two_stage/`

Benodigd op de Pi:

- `stage1_main.onnx`
- `stage1_main.onnx.data`
- `stage2_overige.onnx`
- `stage2_overige.onnx.data`
- `two_stage_metadata.json`

## 3. Installeer runtime dependencies op de Pi 5

```bash
python3 -m venv .venv
source .venv/bin/activate
pip install onnxruntime pillow numpy
```

## 4. Inference-logica op de Pi (belangrijk)

Gebruik altijd deze volgorde:

1. Draai **Stage 1 ONNX** (`stage1_main.onnx`) op de input-foto
2. Neem de hoofdklasse met hoogste score
3. Als hoofdklasse **niet** `Overige` is: dat is je eindresultaat
4. Als hoofdklasse **wel** `Overige` is: draai **Stage 2 ONNX** (`stage2_overige.onnx`)
5. Combineer resultaat als `Overige/<subklasse>`
6. Gebruik confidence-thresholds voor fallback:
   - lage stage-1 confidence -> bv fallback `Restafval`
   - lage stage-2 confidence -> fallback `Overige`

## 5. Labels niet hardcoden

Lees labels uit `two_stage_metadata.json`:

- `stage1_classes`
- `stage2_overige_classes`
- `main_label_for_stage2`
- `default_fallback`

Zo blijft de Pi-app correct als je later nieuwe modellen exporteert.

## 6. Snelle test op de Pi

Test met een paar bekende afbeeldingen uit verschillende klassen:

- Organisch
- PMD
- Papier
- Restafval
- Overige/* (minstens 2 subklassen)

Controleer of:

- Stage 1 en Stage 2 beide geladen worden
- `Overige` correct naar subklasse gaat
- fallback werkt bij onzekere beelden

## 7. Productie tip

Versiebeheer je modelmap op de Pi, bv:

- `models/two_stage/v1/...`
- `models/two_stage/v2/...`

Dan kan je veilig terugrollen als een nieuwe export slechter presteert.

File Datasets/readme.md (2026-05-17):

# Datasets en model-artifacts

In deze map verwijzen we naar de externe bestanden die nodig zijn om het project opnieuw op te bouwen.

## Kaggle-links

- Originele/normale foto's: [Smart Bin Original Images](https://www.kaggle.com/datasets/maartenaudenaert/smart-bin-original-images)
- Crops voor het finale model: [Smart Bin Classifier Crops](https://www.kaggle.com/datasets/maartenaudenaert/smart-bin-classifier-crops)
- Zware modelbestanden en trainingsoutputs: [Smart Bin Model Artifacts](https://www.kaggle.com/datasets/maartenaudenaert/smart-bin-model-artifacts)

## Waarom niet alles in GitHub?

De originele datasets en de zwaardere modelbestanden zijn te groot of te onhandig om als gewone Git-bestanden in de repository te bewaren.

Daarom gebruiken we deze verdeling:

- GitHub: code, documentatie, configuratie en het compacte referentiepakket
- Kaggle: originele foto's, cropdataset en zware trainingsartifacts

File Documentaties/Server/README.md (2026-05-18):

# Smart Bin modeltraining documentatie

Deze map bevat de documentatie en bestanden om het huidige smart-bin trainingsresultaat serverkant te begrijpen en opnieuw te maken.

Het gaat hier over de training en export van de modellen, niet over de installatie op de Raspberry Pi zelf.

## Inhoud

```text
documentatie/
|-- README.md
|-- Handleiding/
|   |-- README.md
|   |-- 01_vm_en_project/
|   |-- 02_dependencies/
|   |-- 03_dataset/
|   |-- 04_detector/
|   |-- 05_crop_classifier/
|   |-- 06_export_modelpakket/
|   `-- 07_controle_en_github/
`-- Bestanden/
    |-- README.md
    |-- MANIFEST.txt
    |-- LOCAL_MANIFEST.txt
    |-- Huidig_modelpakket_finalmodel/
    |-- two_stage_training_outputs/
    |-- Gebruikte_detector/
    `-- Scripts_en_config/
```

## Waarvoor dient deze map?

- [Handleiding/](Handleiding/README.md) legt stap voor stap uit hoe je de dataset, detector, cropdataset, two-stage classifier en exports opnieuw maakt.
- [Bestanden/](Bestanden/README.md) bevat de echte referentiebestanden, scripts, configs en metadata die bij het huidige resultaat horen.

## Huidig referentiemodel

Het modelpakket dat nu als referentie gebruikt wordt:

```text
/root/smart_bin_project/finalmodel
```

In deze documentatiemap staat dat onder:

[Bestanden/Huidig_modelpakket_finalmodel](Bestanden/Huidig_modelpakket_finalmodel/)

## Snel starten

1. Lees [Handleiding/README.md](Handleiding/README.md).
2. Begin vanaf nul met [01_vm_en_project](Handleiding/01_vm_en_project/README.md).
3. Controleer [Bestanden/README.md](Bestanden/README.md).
4. Gebruik [Bestanden/MANIFEST.txt](Bestanden/MANIFEST.txt) om te zien welke artifacts bij het referentieresultaat horen.
5. Controleer [Bestanden/LOCAL_MANIFEST.txt](Bestanden/LOCAL_MANIFEST.txt) voor de GitHub-versie van deze map.

## Handleidingen per onderdeel

- [VM en projectmap maken](Handleiding/01_vm_en_project/README.md)
- [Dependencies installeren](Handleiding/02_dependencies/README.md)
- [Dataset voorbereiden](Handleiding/03_dataset/README.md)
- [YOLO-detector trainen of klaarzetten](Handleiding/04_detector/README.md)
- [Cropdataset en two-stage classifier trainen](Handleiding/05_crop_classifier/README.md)
- [Exporteren en modelpakket maken](Handleiding/06_export_modelpakket/README.md)
- [Controle, GitHub en grote bestanden](Handleiding/07_controle_en_github/README.md)

## Snelle links naar belangrijke bestanden en downloads

- Finale cropdataset op Kaggle: [Smart Bin Classifier Crops](https://www.kaggle.com/datasets/maartenaudenaert/smart-bin-classifier-crops)
- Originele foto's op Kaggle: [Smart Bin Original Images](https://www.kaggle.com/datasets/maartenaudenaert/smart-bin-original-images)
- Zware model-artifacts op Kaggle: [Smart Bin Model Artifacts](https://www.kaggle.com/datasets/maartenaudenaert/smart-bin-model-artifacts)
- Huidige metadata: [two_stage_metadata.json](Bestanden/Huidig_modelpakket_finalmodel/two_stage_metadata.json)
- Huidige detector in het pakket: [best.pt](Bestanden/Huidig_modelpakket_finalmodel/best.pt)
- Detector gebruikt om crops te bouwen: [Gebruikte_detector/README.md](Bestanden/Gebruikte_detector/README.md)
- Two-stage trainingsoutputs: [two_stage_training_outputs/README.md](Bestanden/two_stage_training_outputs/README.md)
- Detector ONNX: [yolov8_detector.onnx](Bestanden/Huidig_modelpakket_finalmodel/yolov8_detector.onnx)
- Stage 1 ONNX: [stage1_main.onnx](Bestanden/Huidig_modelpakket_finalmodel/stage1_main.onnx)
- Stage 2 ONNX: [stage2_overige.onnx](Bestanden/Huidig_modelpakket_finalmodel/stage2_overige.onnx)
- Trainingsscript crops: [train_two_stage_crops.py](Bestanden/Scripts_en_config/train_two_stage_crops.py)
- Exportscript ONNX: [export_two_stage_onnx.py](Bestanden/Scripts_en_config/export_two_stage_onnx.py)
- Requirements: [requirements.txt](Bestanden/Scripts_en_config/requirements.txt)

Opmerking: `yolov8_detector.onnx` is de bestandsnaam die in het huidige pakket gebruikt wordt. In de uitleg noemen we dit gewoon de YOLO-detector. Er staan ook YOLOv11-runs op de VM, maar de metadata van het huidige finale pakket verwijst naar de detectorrun `garbage_detector_l_fallback_aware_768-6`.

## Belangrijke GitHub-opmerking

Deze repo bevat bewust niet alle zware trainingsbestanden als gewone Git-bestanden.

De gekozen verdeling is:

- GitHub voor code, documentatie, scripts, configs en het compacte referentiepakket
- Kaggle voor originele foto's, crops en zware model-artifacts

Daardoor blijven de links werkbaar en kan het project toch volledig opnieuw opgebouwd worden.

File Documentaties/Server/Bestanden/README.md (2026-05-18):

# Bestanden

Deze map bevat de referentiebestanden die horen bij het huidige trainingsresultaat.

De README's in de andere mappen leggen uit hoe je ze gebruikt en opnieuw maakt.

## Structuur

```text
Bestanden/
|-- README.md
|-- MANIFEST.txt
|-- LOCAL_MANIFEST.txt
|-- Huidig_modelpakket_finalmodel/
|-- two_stage_training_outputs/
|-- Gebruikte_detector/
`-- Scripts_en_config/
```

## Wat staat lokaal in GitHub?

In deze repo houden we vooral bij:

- het compacte huidige modelpakket
- scripts en configuratie
- manifesten en documentatie

De zwaardere trainingsbestanden staan bewust op Kaggle:

[Smart Bin Model Artifacts](https://www.kaggle.com/datasets/maartenaudenaert/smart-bin-model-artifacts)

## `Huidig_modelpakket_finalmodel`

Dit is het huidige modelpakket dat als referentie gebruikt wordt.

Belangrijkste bestanden:

- [best.pt](Huidig_modelpakket_finalmodel/best.pt)
- [yolov8_detector.onnx](Huidig_modelpakket_finalmodel/yolov8_detector.onnx)
- [stage1_main.onnx](Huidig_modelpakket_finalmodel/stage1_main.onnx)
- [stage1_main.onnx.data](Huidig_modelpakket_finalmodel/stage1_main.onnx.data)
- [stage2_overige.onnx](Huidig_modelpakket_finalmodel/stage2_overige.onnx)
- [stage2_overige.onnx.data](Huidig_modelpakket_finalmodel/stage2_overige.onnx.data)
- [two_stage_metadata.json](Huidig_modelpakket_finalmodel/two_stage_metadata.json)
- [classifier.py](Huidig_modelpakket_finalmodel/classifier.py)
- [detector.py](Huidig_modelpakket_finalmodel/detector.py)
- [main.py](Huidig_modelpakket_finalmodel/main.py)
- [pi_inference_two_stage.py](Huidig_modelpakket_finalmodel/pi_inference_two_stage.py)
- [hailo_two_stage_main.py](Huidig_modelpakket_finalmodel/hailo_two_stage_main.py)
- [vul_detector_na_training.sh](Huidig_modelpakket_finalmodel/vul_detector_na_training.sh)
- [LEES_MIJ_PI5_HAILO_FINALMODEL.md](Huidig_modelpakket_finalmodel/LEES_MIJ_PI5_HAILO_FINALMODEL.md)

Dit komt overeen met de servermap:

```text
/root/smart_bin_project/finalmodel
```

Opmerking: `yolov8_detector.onnx` is een bestaande bestandsnaam in het pakket.
Voor de documentatie noemen we dit de YOLO-detector export. Hernoem dit bestand
niet zomaar, want scripts kunnen exact deze naam verwachten.

## `two_stage_training_outputs`

Deze map bevat in GitHub alleen uitleg en verwijzingen.

De echte trainingsoutputs staan op Kaggle:

- [Smart Bin Model Artifacts](https://www.kaggle.com/datasets/maartenaudenaert/smart-bin-model-artifacts)
- [two_stage_training_outputs/README.md](two_stage_training_outputs/README.md)

Die komen van:

```text
/root/smart_bin_project/models/two_stage_crops
```

## `Gebruikte_detector`

Deze map bevat in GitHub alleen uitleg en verwijzingen.

De detector die gebruikt werd om de cropdataset te bouwen staat op Kaggle:

- [Smart Bin Model Artifacts](https://www.kaggle.com/datasets/maartenaudenaert/smart-bin-model-artifacts)
- [Gebruikte_detector/README.md](Gebruikte_detector/README.md)

Origineel serverpad:

```text
/root/smart_bin_project/runs/detect_strong/garbage_detector_l_fallback_aware_768-6/weights/best.pt
```

## `Scripts_en_config`

Deze map bevat de scripts en configuratiebestanden die nodig zijn om training en export opnieuw te doen.

Belangrijkste bestanden:

- [train_two_stage_crops.py](Scripts_en_config/train_two_stage_crops.py)
- [export_two_stage_onnx.py](Scripts_en_config/export_two_stage_onnx.py)
- [train_two_stage.py](Scripts_en_config/train_two_stage.py)
- [train_yolo_l.py](Scripts_en_config/train_yolo_l.py)
- [train_yolo_until_target.py](Scripts_en_config/train_yolo_until_target.py)
- [verzamel_pi_bestanden.sh](Scripts_en_config/verzamel_pi_bestanden.sh)
- [requirements.txt](Scripts_en_config/requirements.txt)
- [dataset.yaml](Scripts_en_config/dataset.yaml)
- [dataset_extended.yaml](Scripts_en_config/dataset_extended.yaml)
- [yolov11x_data.yaml](Scripts_en_config/yolov11x_data.yaml)

## Manifest

[MANIFEST.txt](MANIFEST.txt) bevat een lijst van alle bestanden in deze map zoals ze op de server geplaatst zijn.

[LOCAL_MANIFEST.txt](LOCAL_MANIFEST.txt) beschrijft welke bestanden bewust lokaal in GitHub staan en welke via Kaggle gedownload moeten worden.

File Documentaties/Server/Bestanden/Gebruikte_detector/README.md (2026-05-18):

# Gebruikte detector

Deze map bevat in GitHub geen zware `.pt` binary, maar wel de uitleg over welke detector gebruikt werd.

## Bestand

De detector die gebruikt werd om de cropdataset te bouwen is:

- `best_detector_used_for_crops.pt`

## Download

Download dit bestand via:

[Smart Bin Model Artifacts](https://www.kaggle.com/datasets/maartenaudenaert/smart-bin-model-artifacts)

In die Kaggle dataset zit een tarbestand `used_crop_detector.tar` met daarin:

```text
used_crop_detector/
`-- best_detector_used_for_crops.pt
```

## Origineel serverpad

```text
/root/smart_bin_project/runs/detect_strong/garbage_detector_l_fallback_aware_768-6/weights/best.pt
```

## Opmerking

Deze detector is gebruikt om de objectcrops uit de originele foto's te maken. Het finale modelpakket bevat daarnaast ook een compactere `best.pt` in:

```text
/root/smart_bin_project/finalmodel
```

Voor exacte reproductie van de cropbouw gebruik je de detector uit de Kaggle model-artifacts.

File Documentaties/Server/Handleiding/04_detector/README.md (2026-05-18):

# 4. YOLO-detector trainen of klaarzetten

De detector zoekt het afvalobject in de foto. Daarna kan de classifier op een crop trainen in plaats van op de volledige afbeelding.

Korte uitleg:

- `YOLO`: het detectiemodel dat objecten en bounding boxes vindt.
- `best.pt`: het beste detectorbestand uit een trainingsrun.
- `mAP50`: score die aangeeft hoe goed de detector objecten vindt.

Opmerking: op de VM bestaan ook YOLOv11-runs. De metadata van het huidige finale pakket verwijst echter naar de detectorrun `garbage_detector_l_fallback_aware_768-6`. In het modelpakket heet de export `yolov8_detector.onnx`; dat is een legacy bestandsnaam die de code verwacht. Daarom spreken we in de handleiding meestal over de YOLO-detector in het algemeen.

## 4.1 Keuze: bestaande detector of nieuwe training

Voor exacte reproductie gebruik je de bestaande detector uit:

- [Smart Bin Model Artifacts](https://www.kaggle.com/datasets/maartenaudenaert/smart-bin-model-artifacts)
- [Gebruikte_detector/README.md](../../Bestanden/Gebruikte_detector/README.md)

Origineel serverpad:

```text
/root/smart_bin_project/runs/detect_strong/garbage_detector_l_fallback_aware_768-6/weights/best.pt
```

Als je echt vanaf nul werkt, moet je deze detector eerst opnieuw trainen.

## 4.2 Scripts

Beschikbare scripts:

- [train_yolo_l.py](../../Bestanden/Scripts_en_config/train_yolo_l.py)
- [train_yolo_until_target.py](../../Bestanden/Scripts_en_config/train_yolo_until_target.py)

`train_yolo_l.py` is eenvoudiger. `train_yolo_until_target.py` is uitgebreider en kan meerdere pogingen doen tot een doelmetric gehaald wordt.

## 4.3 Dataset voorbereiden voor YOLO

YOLO heeft een train/val lijst en YAML nodig:

```text
yolo_train.txt
yolo_val.txt
dataset.yaml
```

## 4.4 Eenvoudige training

```bash
cd /root/smart_bin_project
source .venv/bin/activate
python3 train_yolo_l.py
```

Belangrijke instellingen uit het script:

```text
epochs=80
imgsz=640
batch=16
device=0
patience=15
```

Wat betekent dit kort?

- `epochs`: hoe vaak het model door de trainingsdata gaat.
- `imgsz`: beeldgrootte waarmee YOLO traint.
- `batch`: hoeveel beelden tegelijk door de GPU gaan.
- `device=0`: gebruik GPU 0.
- `patience`: stop als er zoveel epochs geen verbetering is.

## 4.5 Detector exporteren naar ONNX

Voor de detector die in het huidige model gebruikt werd:

```bash
yolo export model=/root/smart_bin_project/runs/detect_strong/garbage_detector_l_fallback_aware_768-6/weights/best.pt format=onnx imgsz=768
```

Het exportbestand heet meestal:

```text
best.onnx
```

Voor het modelpakket moet dit worden:

```text
yolov8_detector.onnx
```

Laat die naam staan tenzij je ook de code aanpast die dit bestand inlaadt.

Referentie:

[yolov8_detector.onnx](../../Bestanden/Huidig_modelpakket_finalmodel/yolov8_detector.onnx)

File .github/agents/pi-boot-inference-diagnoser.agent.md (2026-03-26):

---
name: Pi Boot Inference Diagnoser
description: "Use when diagnosing why Raspberry Pi project services fail at boot/startup (systemd, environment, paths, permissions, display, Python venv), including inference_gui and related services. Trigger phrases: pi startup failure, service won't start, boot issue, inference gui not launching, systemd diagnostics."
tools: [read, search, execute]
argument-hint: "Describe the startup failure symptom, expected behavior, and any known logs or service names."
user-invocable: true
---
You are a specialist in Raspberry Pi boot-time service diagnostics for Python apps in this project.

Your job is to find why a service does not start automatically at boot and provide a concrete, verifiable fix plan with proposed (not applied) edits.

## Constraints
- DO NOT make destructive system changes.
- DO NOT guess root causes without evidence from code, service files, and logs.
- DO NOT apply edits directly.
- ONLY recommend fixes that can be validated with repeatable checks.

## Approach
1. Inspect service units, ExecStart, WorkingDirectory, user, environment, and dependencies.
2. Inspect app entry points and imports for boot-context problems (relative paths, missing display, permissions, unavailable devices).
3. Validate Python interpreter and virtual environment paths used by the service.
4. Correlate with startup logs and provide ranked likely root causes.
5. Return a smallest-safe fix plan with verification commands and explicit proposed diffs.

## Output Format
Return sections in this exact order:
1. Observed Evidence
2. Most Likely Root Cause
3. Alternative Causes To Rule Out
4. Minimal Fix
5. Verification Steps
6. Rollback Plan

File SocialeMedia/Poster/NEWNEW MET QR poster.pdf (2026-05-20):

# SLIMME AFVALCONTAINER

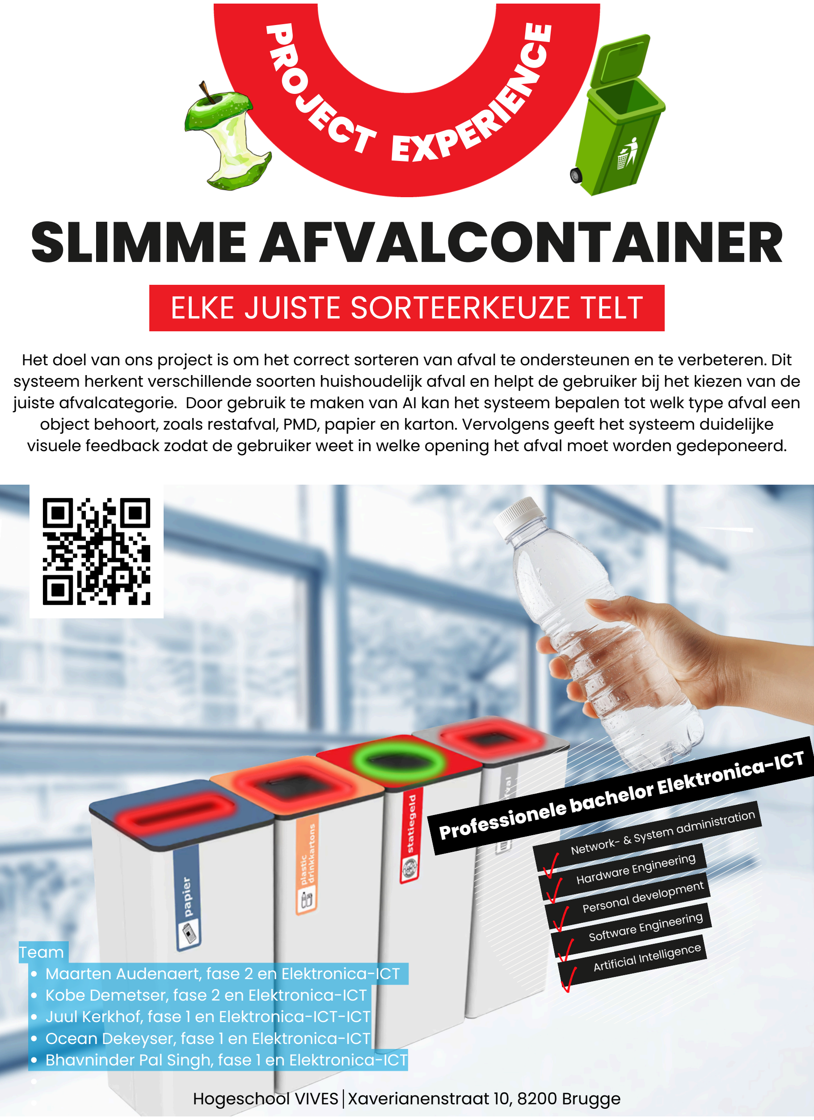
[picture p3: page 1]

# ELKE JUISTE SORTEERKEUZE TELT

### Professionele bachelor Elektronica-ICT

Software Engineering

Hardware Engineering
Personal development

Network- & System administration

Team
Maarten Audenaert, fase 2 en Elektronica-ICT Kobe Demetser, fase 2 en Elektronica-ICT Juul Kerkhof, fase 1 en Elektronica-ICT-ICT Ocean Dekeyser, fase 1 en Elektronica-ICT Bhavninder Pal Singh, fase 1 en Elektronica-ICT

# PROJECT EXPERIENCE

Hogeschool VIVES Xaverianenstraat 10, 8200 Brugge

Artificial Intelligence

Het doel van ons project is om het correct sorteren van afval te ondersteunen en te verbeteren. Dit systeem herkent verschillende soorten huishoudelijk afval en helpt de gebruiker bij het kiezen van de juiste afvalcategorie. Door gebruik te maken van AI kan het systeem bepalen tot welk type afval een object behoort, zoals restafval, PMD, papier en karton. Vervolgens geeft het systeem duidelijke visuele feedback zodat de gebruiker weet in welke opening het afval moet worden gedeponeerd.

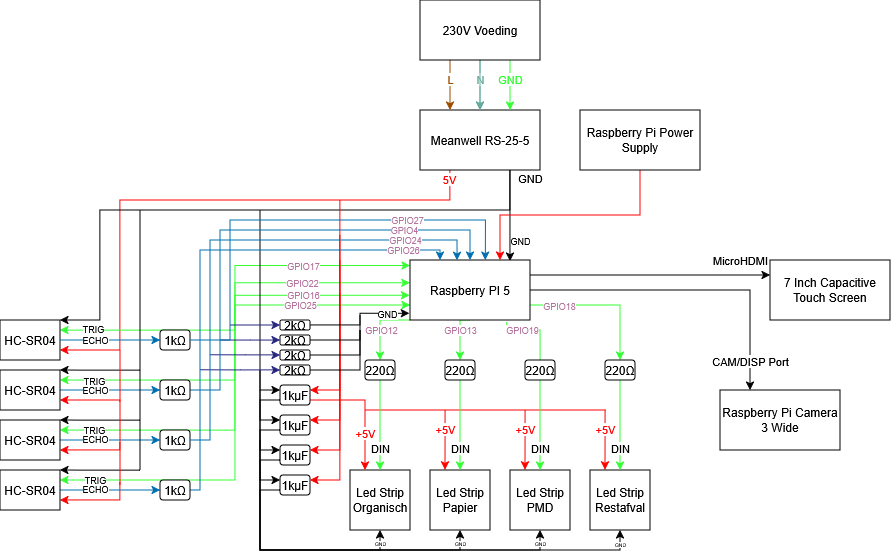
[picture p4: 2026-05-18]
Architectuur/SlimmeAfvalContainer_Architectuur.png

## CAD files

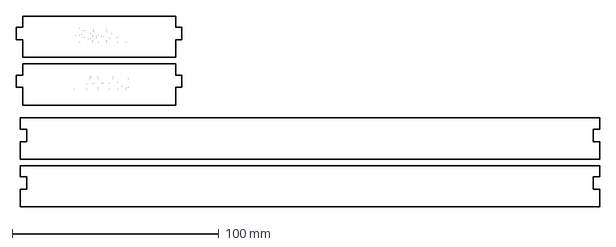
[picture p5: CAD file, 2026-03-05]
Behuizingen/Behuizing LED/box small.dxf
281.9 x 92.2 mm

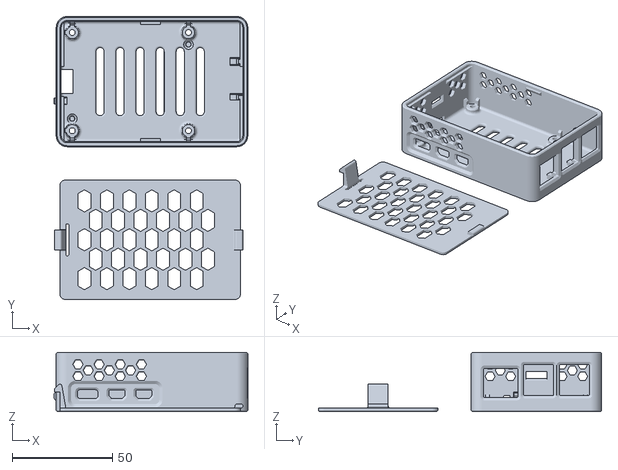
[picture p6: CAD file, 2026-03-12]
Behuizingen/Behuizing Pi/Pi_5-case.stl
96.6 x 141.2 x 29.5

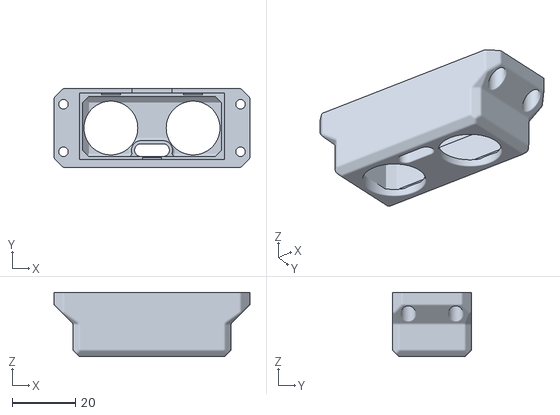
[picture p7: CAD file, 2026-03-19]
Behuizingen/Behuizing Ultrasone Sensor/Sensorhouder_Ultrasonesensor_HC-SR04.stl
62.0 x 25.0 x 20.4

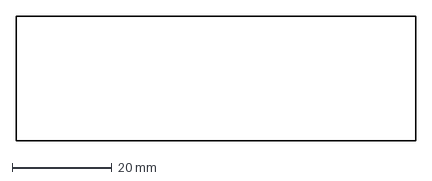
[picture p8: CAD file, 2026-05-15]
Behuizingen/Camera_Display_Extension/Kabels Ultrasoon.dxf
80.0 x 25.0 mm

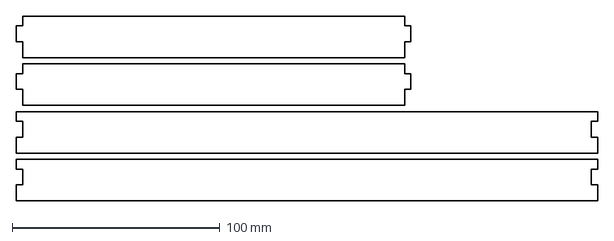
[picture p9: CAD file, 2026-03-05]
Behuizingen/Behuizing LED/boxBIG.dxf
280.0 x 89.0 mm

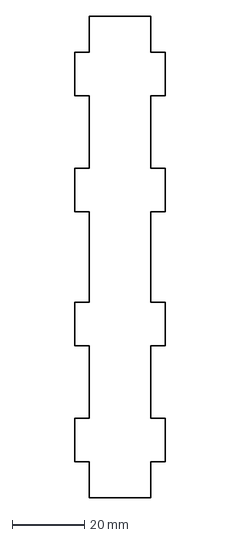
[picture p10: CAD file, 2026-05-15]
Behuizingen/Camera_Display_Extension/Kort_Zijkant.dxf
25.0 x 133.0 mm

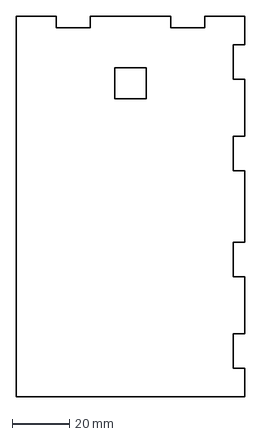
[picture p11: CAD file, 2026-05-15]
Behuizingen/Camera_Display_Extension/Lang.dxf
80.0 x 133.0 mm

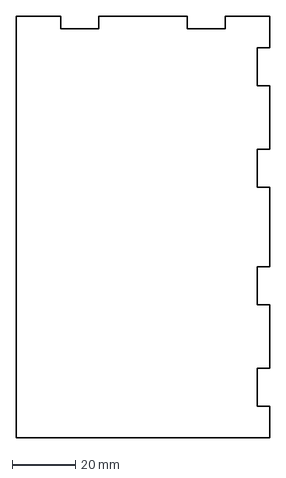
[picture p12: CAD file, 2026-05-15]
Behuizingen/Camera_Display_Extension/Lang_Achter.dxf
80.0 x 133.0 mm

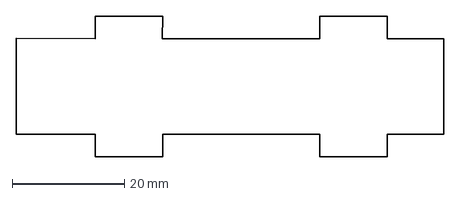
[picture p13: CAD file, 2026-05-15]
Behuizingen/Camera_Display_Extension/Kort_Boven.dxf
76.0 x 25.0 mm

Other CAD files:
Behuizingen/Touchscreen_Display/top.gcode.3mf
Behuizingen/Touchscreen_Display/bottom.gcode.3mf
Behuizingen/Behuizing Algemeen V1/Dak.f3d
Behuizingen/Behuizing Algemeen V1/Muur Kort.f3d
Behuizingen/Behuizing Algemeen V1/Muur Lang.f3d
Behuizingen/Bodem plaat/Muur Klein.f3d
Behuizingen/Bodem plaat/Muur Lang.f3d
Behuizingen/Bodem plaat/Plaat.f3d
Behuizingen/Ultra soon steun/ultra Top.f3d
Behuizingen/Ultra soon steun/ultra achter.f3d
Behuizingen/Ultra soon steun/ultra schuin.f3d
Behuizingen/Volledig Deksel Lasercut/Deksel Volledig.f3z
Behuizingen/ZijTafel/Tafel.f3z

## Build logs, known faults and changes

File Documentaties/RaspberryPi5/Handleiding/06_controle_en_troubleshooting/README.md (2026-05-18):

# 6. Controle en troubleshooting

Gebruik dit hoofdstuk om snel te controleren of de Pi-runtime gezond is.

## 6.1 Service controleren

```bash
systemctl status garbagedetection-gui.service --no-pager -l
```

Goed:

```text
Active: active (running)
```

Fout:

```text
activating (auto-restart)
failed
```

Bekijk dan logs:

```bash
journalctl -u garbagedetection-gui.service -n 120 --no-pager
```

## 6.2 Proces controleren

```bash
ps -ef | grep -E 'garbagedetection_gui|start_garbage_gui' | grep -v grep
```

Verwacht iets zoals:

```text
/home/kobe/SlimmeAfvalcontainer/venv_ssp/bin/python /home/kobe/SlimmeAfvalcontainer/test11mei_light_crops/garbagedetection_gui.py --fullscreen
```

Door de symlink komt dit effectief uit bij:

```text
/home/kobe/SlimmeAfvalcontainer/finalmodel
```

## 6.3 Modelbestanden controleren

```bash
cd /home/kobe/SlimmeAfvalcontainer/finalmodel
ls -lah yolov8_detector.onnx stage1_main.onnx stage2_overige.onnx two_stage_metadata.json
```

Als een `.onnx.data` bestand ontbreekt, kan ONNX Runtime het model mogelijk niet
laden.

## 6.4 Python syntax controleren

```bash
cd /home/kobe/SlimmeAfvalcontainer/finalmodel
python3 -m py_compile garbagedetection_gui.py detector.py classifier.py led_controller.py ultrasone_controller.py
```

Geen output betekent normaal dat de syntax correct is.

## 6.5 Camera hangt bij LED-actie

Als de camera lijkt vast te hangen wanneer `Overige` gedetecteerd wordt, check
of `reject_blink` non-blocking is gemaakt.

In `led_controller.py` moet `_send_command_via_subprocess()` voor
`reject_blink` `subprocess.Popen(...)` gebruiken, niet alleen
`subprocess.run(...)`.

Controle:

```bash
grep -nE 'reject_blink|Popen|subprocess.run' /home/kobe/SlimmeAfvalcontainer/Code\ PI/led_controller.py
grep -nE 'reject_blink|Popen|subprocess.run' /home/kobe/SlimmeAfvalcontainer/finalmodel/led_controller.py
```

## 6.6 Foto's worden opgeslagen

De runtime hoort geen foto's meer op te slaan.

Controle:

```bash
find /home/kobe/SlimmeAfvalcontainer/finalmodel -maxdepth 1 -type d -name captures
grep -n "_save_capture_photo(pil_img)" /home/kobe/SlimmeAfvalcontainer/finalmodel/garbagedetection_gui.py
```

Als `captures` bestaat, kan die verwijderd worden:

```bash
sudo rm -rf /home/kobe/SlimmeAfvalcontainer/finalmodel/captures
```

## 6.7 Autostart na reboot testen

Herstart de Pi:

```bash
sudo reboot
```

Na opnieuw verbinden:

```bash
systemctl status garbagedetection-gui.service --no-pager -l
```

Als de service enabled is en de status running is, start de GUI correct mee op.

Controle enabled:

```bash
systemctl is-enabled garbagedetection-gui.service
```

Verwacht:

```text
enabled
```

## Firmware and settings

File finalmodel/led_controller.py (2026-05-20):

"""GPIO controller voor 4 WS2812B strips direct op Raspberry Pi.

Pin mapping (BCM):
    REST      -> GPIO18
    KARTON    -> GPIO13
    ORGANISCH -> GPIO12
    PMD       -> GPIO19

Deze module houdt dezelfde `send_command(cmd)` API aan als de oude UART-versie,
zodat hij direct gebruikt kan worden door `inference_gui.py`.
"""

from __future__ import annotations

import os
import subprocess
import sys
import threading
import time
from enum import Enum, auto

import board
try:
    import neopixel
    _NEOPIXEL_IMPORT_ERROR: Exception | None = None
except Exception as exc:
    neopixel = None  # type: ignore[assignment]
    _NEOPIXEL_IMPORT_ERROR = exc

# ── Configuratie ─────────────────────────────────────────────────────────────
# Pas deze aan op basis van het aantal leds per strip.
# Huidige hardware:
# - REST: 51
# - KARTON: 38
# - ORGANISCH: 51
# - PMD: 51
DEFAULT_BRIGHTNESS = float(os.getenv("LED_BRIGHTNESS", "0.25"))
MAX_SUPPLY_CURRENT_A = float(os.getenv("LED_MAX_CURRENT_A", "5.0"))
CURRENT_HEADROOM = float(os.getenv("LED_CURRENT_HEADROOM", "0.85"))

PIN_MAP = {
        "rest": board.D18,
        "karton": board.D13,
        "organisch": board.D12,
        "pmd": board.D19,
}

DEFAULT_LED_COUNT_MAP = {
    "rest": int(os.getenv("LED_COUNT_REST", "51")),
    "karton": int(os.getenv("LED_COUNT_KARTON", "38")),
    "organisch": int(os.getenv("LED_COUNT_ORGANISCH", "51")),
    "pmd": int(os.getenv("LED_COUNT_PMD", "51")),
}

COLOR_MAP = {
        "rest": (255, 70, 70),
        "karton": (70, 140, 255),
        "organisch": (0, 255, 0),
        "pmd": (255, 190, 40),
}

RESULT_GREEN = (0, 255, 0)
RESULT_RED = (255, 0, 0)

SPECIAL_COLOR_MAP = {
    "overige": (160, 160, 160),
    "overige_batterijen": (255, 120, 40),
    "overige_elektronica": (255, 60, 60),
    "overige_glas": (40, 190, 170),
    "overige_lightbulbs": (255, 230, 90),
    "overige_metaal": (150, 120, 95),
}

OFF = (0, 0, 0)

class Choice(Enum):
    NONE      = auto()
    PMD       = auto()
    REST      = auto()
    KARTON    = auto()
    ORGANISCH = auto()


class LedController:
    """
    Stuurt commando's naar 4 WS2812B strips op GPIO.

    Methode:
        send_command(cmd: str) -> str
            Accepteert: "pmd", "rest", "karton", "papier",
                        "organisch", "bio", "all", "hit", "off", "reset",
                        plus "overige*" varianten.
            Stuurt leds aan en geeft een status-string terug.
    """

    def __init__(self, led_count_map: dict[str, int] | None = None, brightness: float = DEFAULT_BRIGHTNESS):
        # Process-isolatie als standaard: voorkomt native neopixel crashes in GUI-proces.
        self._proxy_mode = os.getenv("LED_PROCESS_ISOLATION", "1") == "1"
        self.enabled = False
        self.current_choice = Choice.NONE
        self._lock = threading.Lock()
        self._strips: dict[str, neopixel.NeoPixel] = {}
        self._led_count_map: dict[str, int] = {}
        self._max_allowed_current_a = max(0.1, MAX_SUPPLY_CURRENT_A * CURRENT_HEADROOM)

        # Isolatiemodus: LED-IO loopt in een apart proces zodat een native
        # neopixel crash de GUI niet kan neerhalen.
        if self._proxy_mode:
            self.enabled = True
            print("[LED] Process-isolation actief (subprocess mode)")
            return

        if _NEOPIXEL_IMPORT_ERROR is not None:
            print(
                f"[LED] Waarschuwing: neopixel module niet bruikbaar: {_NEOPIXEL_IMPORT_ERROR}\n"
                "  LED-aansturing wordt uitgeschakeld, GUI blijft actief."
            )
            return

        if led_count_map is None:
            led_count_map = DEFAULT_LED_COUNT_MAP.copy()

        try:
            for name, pin in PIN_MAP.items():
                led_count = int(led_count_map.get(name, 1))
                if led_count < 1:
                    led_count = 1
                self._led_count_map[name] = led_count
                self._strips[name] = neopixel.NeoPixel(
                    pin,
                    led_count,
                    brightness=brightness,
                    auto_write=False,
                    pixel_order=neopixel.GRB,
                )

            self._set_all(OFF)
            self.enabled = True
            print("[LED] Controller gereed. 4 strips actief op GPIO 18/13/12/19")
            print(
                f"[LED] Current limiter actief: max {self._max_allowed_current_a:.2f}A "
                f"(supply={MAX_SUPPLY_CURRENT_A:.2f}A, headroom={CURRENT_HEADROOM:.2f})"
            )
        except Exception as exc:
            print(
                f"[LED] Waarschuwing: GPIO/NeoPixel init mislukt: {exc}\n"
                "  Controleer wiring, permissies en rpi_ws281x setup.\n"
                "  LED-aansturing wordt overgeslagen."
            )

    # ── Publieke interface ────────────────────────────────────────────────────

    def _set_all(self, rgb: tuple[int, int, int]) -> None:
        for strip in self._strips.values():
            strip.fill(rgb)
            strip.show()

    @staticmethod
    def _estimate_led_current_a(rgb: tuple[int, int, int]) -> float:
        # WS2812B kanaalstroom benadering: ~20mA per kanaal op 255.
        r, g, b = rgb
        return ((r + g + b) / 255.0) * 0.02

    def _limit_color_for_strip(self, strip_name: str, rgb: tuple[int, int, int]) -> tuple[int, int, int]:
        led_count = self._led_count_map.get(strip_name, 1)
        estimated_total = self._estimate_led_current_a(rgb) * led_count
        if estimated_total <= self._max_allowed_current_a:
            return rgb

        # Schaal RGB proportioneel zodat I_est <= limiet.
        scale = self._max_allowed_current_a / max(estimated_total, 1e-6)
        r, g, b = rgb
        limited = (
            max(0, min(255, int(r * scale))),
            max(0, min(255, int(g * scale))),
            max(0, min(255, int(b * scale))),
        )
        print(
            f"[LED] Current limit toegepast voor {strip_name}: "
            f"{rgb} -> {limited} (est {estimated_total:.2f}A > {self._max_allowed_current_a:.2f}A)"
        )
        return limited

    def _show_bin(self, bin_name: str) -> None:
        self._set_all(OFF)
        strip = self._strips.get(bin_name)
        if strip is not None:
            color = self._limit_color_for_strip(bin_name, COLOR_MAP[bin_name])
            strip.fill(color)
            strip.show()

    def _show_all_bins(self) -> None:
        for name, strip in self._strips.items():
            color = self._limit_color_for_strip(name, COLOR_MAP[name])
            strip.fill(color)
            strip.show()

    def _show_all_color(self, rgb: tuple[int, int, int]) -> None:
        for name, strip in self._strips.items():
            color = self._limit_color_for_strip(name, rgb)
            strip.fill(color)
            strip.show()

    def _blink_all_color(self, rgb: tuple[int, int, int], cycles: int = 6, delay: float = 0.18) -> None:
        for _ in range(cycles):
            self._show_all_color(rgb)
            time.sleep(delay)
            self._set_all(OFF)
            time.sleep(delay)
        self._show_all_color(rgb)

    def _show_selection(self, selected_bin: str) -> None:
        for name, strip in self._strips.items():
            rgb = RESULT_GREEN if name == selected_bin else RESULT_RED
            color = self._limit_color_for_strip(name, rgb)
            strip.fill(color)
            strip.show()

    def send_command(self, cmd: str) -> str:
        """
        Verwerk een commando-string en stuur de strips aan.

        Geeft een status-string terug.
        """
        cmd = cmd.strip().lower()

        if self._proxy_mode:
            return self._send_command_via_subprocess(cmd)

        # Alias voor compatibiliteit met oudere flow.
        if cmd == "papier":
            cmd = "karton"
        elif cmd == "bio":
            cmd = "organisch"

        if not self.enabled:
            print(f"[LED] (uitgeschakeld) commando: {cmd}")
            return f"OK: {cmd.upper()}"

        with self._lock:
            try:
                if cmd in PIN_MAP:
                    self._show_bin(cmd)
                    self.current_choice = {
                        "pmd": Choice.PMD,
                        "rest": Choice.REST,
                        "karton": Choice.KARTON,
                        "organisch": Choice.ORGANISCH,
                    }[cmd]
                    return f"OK: {cmd.upper()}"

                if cmd == "all":
                    self._show_all_bins()
                    self.current_choice = Choice.NONE
                    return "OK: ALL"

                if cmd == "idle":
                    self._show_all_bins()
                    self.current_choice = Choice.NONE
                    return "OK: IDLE"

                if cmd.startswith("confirm_"):
                    # Flash all strips orange 2x to signal successful throw-in, then idle.
                    CONFIRM_COLOR = (255, 120, 0)
                    for _ in range(2):
                        self._show_all_color(CONFIRM_COLOR)
                        time.sleep(0.3)
                        self._set_all(OFF)
                        time.sleep(0.2)
                    self._show_all_bins()
                    self.current_choice = Choice.NONE
                    return "OK: CONFIRM"

                if cmd == "reject":
                    self._show_all_color(RESULT_RED)
                    self.current_choice = Choice.NONE
                    return "OK: REJECT"

                if cmd == "reject_blink":
                    self._blink_all_color(RESULT_RED)
                    self.current_choice = Choice.NONE
                    return "OK: REJECT_BLINK"

                if cmd.startswith("select_"):
                    selected = cmd.removeprefix("select_")
                    if selected in PIN_MAP:
                        self._show_selection(selected)
                        self.current_choice = {
                            "pmd": Choice.PMD,
                            "rest": Choice.REST,
                            "karton": Choice.KARTON,
                            "organisch": Choice.ORGANISCH,
                        }[selected]
                        return f"OK: SELECT_{selected.upper()}"

                if cmd in SPECIAL_COLOR_MAP:
                    self._show_all_color(SPECIAL_COLOR_MAP[cmd])
                    self.current_choice = Choice.NONE
                    return f"OK: {cmd.upper()}"

                if cmd == "hit":
                    # Herhaal laatste keuze.
                    mapping = {
                        Choice.PMD: "pmd",
                        Choice.REST: "rest",
                        Choice.KARTON: "karton",
                        Choice.ORGANISCH: "organisch",
                    }
                    selected = mapping.get(self.current_choice)
                    if selected:
                        self._show_bin(selected)
                    return "OK: HIT"

                if cmd in {"off", "reset"}:
                    self._set_all(OFF)
                    if cmd == "reset":
                        self.current_choice = Choice.NONE
                    return f"OK: {cmd.upper()}"

                return f"UNKNOWN: {cmd}"
            except Exception as exc:
                print(f"[LED] Fout bij commando '{cmd}': {exc}")
                return f"ERROR: {cmd}"

    def _send_command_via_subprocess(self, cmd: str) -> str:
        child_code = (
            "import os,sys; "
            "os.environ['LED_PROCESS_ISOLATION']='0'; "
            "sys.path.insert(0, '/home/kobe/SlimmeAfvalcontainer/Code PI'); "
            "from led_controller import LedController; "
            "c=LedController(); "
            "resp=c.send_command(sys.argv[1]); "
            "print(resp)"
        )
        if cmd == "reject_blink":
            try:
                subprocess.Popen(
                    [sys.executable, "-c", child_code, cmd],
                    stdout=subprocess.DEVNULL,
                    stderr=subprocess.DEVNULL,
                    start_new_session=True,
                )
                return "OK: REJECT_BLINK"
            except Exception as exc:
                print(f"[LED] Subprocess exception: {exc}")
                return f"ERROR: {cmd}"

        try:
            result = subprocess.run(
                [sys.executable, "-c", child_code, cmd],
                capture_output=True,
                text=True,
                timeout=5,
                check=False,
            )
            if result.returncode != 0:
                err = (result.stderr or "").strip()
                print(f"[LED] Subprocess fout ({result.returncode}): {err}")
                return f"ERROR: {cmd}"

            lines = [line.strip() for line in (result.stdout or "").splitlines() if line.strip()]
            if lines:
                return lines[-1]
            return f"OK: {cmd.upper()}"
        except Exception as exc:
            print(f"[LED] Subprocess exception: {exc}")
            return f"ERROR: {cmd}"

    def close(self) -> None:
        """Zet alle leds uit en geef resources vrij."""
        if self._proxy_mode:
            self.send_command("off")
            self.enabled = False
            return

        if not self.enabled:
            return

        with self._lock:
            try:
                self._set_all(OFF)
            finally:
                for strip in self._strips.values():
                    try:
                        strip.deinit()
                    except Exception:
                        pass
                self._strips.clear()
                self.enabled = False


# ── Standalone test ──────────────────────────────────────────────────────────
if __name__ == "__main__":
    import time

    ctrl = LedController()
    for cmd in ["pmd", "rest", "karton", "organisch", "hit", "off"]:
        print(f"Verzonden: {cmd} -> {ctrl.send_command(cmd)}")
        time.sleep(2)
    ctrl.close()

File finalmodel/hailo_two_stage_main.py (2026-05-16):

import cv2
import time
import os
import numpy as np

from classifier import TwoStageGarbageClassifier

# ── Configuratie ─────────────────────────────────────────────────────────────
HEF_MODEL_PATH = "yolov8_detector.hef"  # Het gecompileerde Hailo model
CLASSIFIER_DIR = "."                    # Map met stage1_main.onnx, stage2_overige.onnx en metadata
RESOLUTION     = (1280, 720)
MIN_BOX_AREA   = 3000
MAX_BOX_AREA_RATIO = 0.85
CONF_THRESHOLD = 0.45
NMS_IOU_THRESHOLD = 0.35
MAX_DETECTIONS = 6

CATEGORY_COLORS = {
    "Organisch":   (0,   165, 255),
    "PMD":         (255, 200,   0),
    "Papier":      (100, 200, 100),
    "Restafval":   (80,   80,  80),
    "Overige":     (180, 180, 180),
    "Elektronica": (0,   100, 255),
    "Glas":        (180, 255, 255),
    "Batterijen":  (0,   0,   255),
    "Metaal":      (200, 200, 200),
    "Lightbulbs":  (255, 255, 0),
}

# ── Hailo / PiCamera2 Import ────────────────────────────────────────────────
try:
    from picamera2 import Picamera2
    from picamera2.devices.hailo import Hailo
    HAILO_OK = True
except ImportError:
    HAILO_OK = False
    print("Fout: picamera2 of hailo niet gevonden op dit systeem.")


def parse_hailo_output(hailo_output, orig_w: int, orig_h: int):
    detections = []
    if hailo_output is None:
        return detections

    for detection in hailo_output:
        label_id  = int(detection.get_label())
        conf      = float(detection.get_confidence())
        if conf < CONF_THRESHOLD:
            continue
        bbox = detection.get_bbox()
        x1 = int(bbox.xmin() * orig_w)
        y1 = int(bbox.ymin() * orig_h)
        x2 = int(bbox.xmax() * orig_w)
        y2 = int(bbox.ymax() * orig_h)
        bw, bh = x2 - x1, y2 - y1
        if bw * bh < MIN_BOX_AREA:
            continue
        if (bw * bh) / (orig_w * orig_h) > MAX_BOX_AREA_RATIO:
            continue
        detections.append((x1, y1, x2, y2, conf, label_id))
    return apply_nms(detections)


def apply_nms(detections):
    if not detections:
        return []

    boxes = []
    scores = []
    for x1, y1, x2, y2, conf, _label_id in detections:
        boxes.append([x1, y1, max(1, x2 - x1), max(1, y2 - y1)])
        scores.append(float(conf))

    indices = cv2.dnn.NMSBoxes(boxes, scores, CONF_THRESHOLD, NMS_IOU_THRESHOLD)
    if indices is None or len(indices) == 0:
        return []

    kept = np.array(indices).reshape(-1).astype(int).tolist()
    kept.sort(key=lambda idx: detections[idx][4], reverse=True)
    kept = kept[:MAX_DETECTIONS]
    return [detections[idx] for idx in kept]

def main():
    if not HAILO_OK:
        return
        
    print(f"Laden van Classifiers uit {CLASSIFIER_DIR} op CPU...")
    classifier = TwoStageGarbageClassifier(model_dir=CLASSIFIER_DIR, stage1_threshold=0.60, stage2_threshold=0.55)

    picam2 = Picamera2()
    config = picam2.create_preview_configuration(main={"size": RESOLUTION, "format": "RGB888"})
    picam2.configure(config)

    print(f"Laden van Hailo YOLO model: {HEF_MODEL_PATH}...")
    with Hailo(HEF_MODEL_PATH) as hailo:
        model_h, model_w, _ = hailo.get_input_shape()
        picam2.start()
        print("Camera gestart. Druk op 'Q' om te stoppen.")

        while True:
            t0 = time.time()
            frame = picam2.capture_array()
            h, w = frame.shape[:2]

            # 1. YOLO detectie via Hailo HAT
            resized = cv2.resize(frame, (model_w, model_h))
            hailo_output = hailo.run(resized)
            detections = parse_hailo_output(hailo_output, w, h)

            display = cv2.cvtColor(frame, cv2.COLOR_RGB2BGR)
            
            # 2. Classifier (Stage 1 & 2) via CPU voor elke detectie
            for x1, y1, x2, y2, conf, cls in detections:
                pad = 8
                crop = display[
                    max(0, y1 - pad): min(h, y2 + pad),
                    max(0, x1 - pad): min(w, x2 + pad)
                ]

                # Classificeer de uitsnede
                final_label, clf_conf = classifier.classify(crop)
                
                # Teken box
                main_cat = final_label.split('/')[0] if '/' in final_label else final_label
                color = CATEGORY_COLORS.get(main_cat, (200, 200, 200))
                cv2.rectangle(display, (x1, y1), (x2, y2), color, 2)

                text = f"{final_label} ({clf_conf:.0%})"
                (tw, th), _ = cv2.getTextSize(text, cv2.FONT_HERSHEY_SIMPLEX, 0.55, 1)
                cv2.rectangle(display, (x1, y1 - th - 8), (x1 + tw + 6, y1), color, -1)
                cv2.putText(display, text, (x1 + 3, y1 - 4), cv2.FONT_HERSHEY_SIMPLEX, 0.55, (255, 255, 255), 1)

            fps = 1 / (time.time() - t0)
            cv2.putText(display, f"FPS: {fps:.1f} [Hailo + CPU Classifier]", (10, 28),
                        cv2.FONT_HERSHEY_SIMPLEX, 0.65, (255, 255, 255), 2)

            cv2.imshow("Smart Bin 2-Stage", display)
            if cv2.waitKey(1) & 0xFF == ord("q"):
                break

        picam2.stop()
    cv2.destroyAllWindows()

if __name__ == "__main__":
    main()

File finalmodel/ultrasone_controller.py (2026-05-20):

from __future__ import annotations

import threading
import time

try:
    import RPi.GPIO as GPIO  # type: ignore
    GPIO_AVAILABLE = True
except ImportError:
    GPIO_AVAILABLE = False


class UltrasonicMonitor:
    """Background monitor for bin fill-level using HC-SR04 sensors."""

    SENSOR_MAP = {
        "rest": {"trig": 25, "echo": 26},
        "pmd": {"trig": 22, "echo": 4},
        "papier": {"trig": 16, "echo": 24},
        # Default Organisch sensor pins (can be overridden from CLI).
        "org": {"trig": 17, "echo": 27},
    }
    # Sensor points to the bin corner (diagonal line), so use calibrated
    # empty-bin reference distance instead of vertical height.
    EMPTY_DISTANCE_CM = 75.0
    THROW_THRESHOLD_CM = 15.0
    THROW_DEBOUNCE_S = 1.5
    THROW_CONFIRM_DELAY_S = 0.2
    THROW_CONFIRM_SAMPLES = 2
    THROW_STATUS_HOLD_S = 2.0
    REASON_LABELS = {
        "ok": "OK",
        "stuck_high_pretrigger": "ECHO_HIGH",
        "no_rising_echo": "NO_ECHO",
        "echo_too_long": "ECHO_LONG",
        "out_of_range": "RANGE",
        "unknown": "UNKNOWN",
    }

    def __init__(
        self,
        debug: bool = False,
        debug_every_cycles: int = 1,
        sensor_overrides: dict[str, dict[str, int] | None] | None = None,
    ) -> None:
        self.enabled = GPIO_AVAILABLE
        self.debug = bool(debug)
        self.debug_every_cycles = max(1, int(debug_every_cycles))
        self._running = False
        self._thread: threading.Thread | None = None
        self._lock = threading.Lock()
        self._cycle_count = 0
        self.sensor_map = dict(self.SENSOR_MAP)
        if sensor_overrides:
            for key, cfg in sensor_overrides.items():
                if key in self.sensor_map:
                    self.sensor_map[key] = cfg
        self._status: dict[str, dict[str, object]] = {
            k: {
                "fill_pct": None,
                "is_full": False,
                "threw_object": False,
                "diag": "",
                "text": "onbekend" if self.sensor_map.get(k) else "n.v.t.",
            }
            for k in self.sensor_map
        }
        self._prev_distance: dict[str, float | None] = {k: None for k in self.sensor_map}
        self._last_throw_at: dict[str, float] = {k: 0.0 for k in self.sensor_map}
        if not self.enabled:
            return
        try:
            GPIO.setmode(GPIO.BCM)
            GPIO.setwarnings(False)
            for cfg in self.sensor_map.values():
                if not cfg:
                    continue
                GPIO.setup(cfg["trig"], GPIO.OUT, initial=GPIO.LOW)
                GPIO.setup(cfg["echo"], GPIO.IN, pull_up_down=GPIO.PUD_DOWN)
            time.sleep(0.2)
            self._running = True
            self._thread = threading.Thread(target=self._loop, daemon=True)
            self._thread.start()
            self._debug_print("Ultrasonic monitor gestart")
        except Exception as exc:
            print(f"[Ultrasoon] Init mislukt: {exc}")
            self.enabled = False

    def close(self) -> None:
        if not self.enabled:
            return
        self._running = False
        if self._thread and self._thread.is_alive():
            self._thread.join(timeout=1.0)
        try:
            GPIO.cleanup()
        except Exception:
            pass

    def snapshot(self) -> dict[str, dict[str, object]]:
        with self._lock:
            return {k: dict(v) for k, v in self._status.items()}

    def _loop(self) -> None:
        while self._running:
            self._cycle_count += 1
            should_print_cycle = self.debug and (self._cycle_count % self.debug_every_cycles == 0)
            for key, cfg in self.sensor_map.items():
                if not cfg:
                    continue
                d, diag = self._measure_average(cfg, samples=2)
                fill = self._calc_fill_pct(d)
                is_full = (d is not None and (d < 5.0 or fill >= 95))
                now = time.time()
                prev = self._prev_distance.get(key)
                threw_object = self._detect_throw_event(key, cfg, prev, d, now)

                if d is not None:
                    self._prev_distance[key] = d

                if d is None:
                    txt = ""
                elif is_full:
                    txt = f"VOL ({fill}%)"
                elif threw_object or (now - self._last_throw_at.get(key, 0.0) <= self.THROW_STATUS_HOLD_S):
                    txt = f"{fill}%"
                elif fill >= 80:
                    txt = f"bijna vol ({fill}%)"
                else:
                    txt = f"{fill}%"
                if should_print_cycle:
                    trig = cfg["trig"]
                    echo = cfg["echo"]
                    d_txt = f"{d:.1f}cm" if d is not None else "None"
                    reason = self.REASON_LABELS.get(str(diag.get("reason", "unknown")), str(diag.get("reason", "unknown")))
                    samples_txt = str(diag["samples"])
                    self._debug_print(
                        f"{key.upper():<6} | T:{trig:>2} E:{echo:>2} | D:{d_txt:>8} | F:{fill:>3}% | "
                        f"S:{diag['ok_samples']}/{diag['total_samples']} | R:{reason:<9} | "
                        f"THROW:{'Y' if threw_object else 'N'} | [{samples_txt}]"
                    )
                threw_visible = threw_object or (now - self._last_throw_at.get(key, 0.0) <= self.THROW_STATUS_HOLD_S)
                with self._lock:
                    self._status[key] = {
                        "fill_pct": fill if d is not None else None,
                        "is_full": is_full,
                        "threw_object": threw_visible,
                        "diag": str(diag.get("reason", "")),
                        "text": txt,
                    }
                time.sleep(0.01)
            if should_print_cycle:
                self._debug_print("-" * 72)
            time.sleep(0.05)

    @staticmethod
    def _measure_distance(cfg: dict, timeout: float = 0.038) -> tuple[float | None, str | None]:
        t0 = time.time()
        while GPIO.input(cfg["echo"]) == 1:
            if time.time() - t0 >= timeout:
                return None, "stuck_high_pretrigger"
        GPIO.output(cfg["trig"], GPIO.HIGH)
        time.sleep(0.00001)
        GPIO.output(cfg["trig"], GPIO.LOW)

        t1 = time.time()
        while GPIO.input(cfg["echo"]) == 0:
            if time.time() - t1 >= timeout:
                return None, "no_rising_echo"
        start = time.time()
        while GPIO.input(cfg["echo"]) == 1:
            if time.time() - start >= timeout:
                return None, "echo_too_long"
        stop = time.time()
        d = ((stop - start) * 34300.0) / 2.0
        if not (2.0 < d <= 400.0):
            return None, "out_of_range"
        return d, None
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

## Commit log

2026-02-12 Eerste testcode voor Ledstrip aansturing
2026-02-26 Add Smart Bin Display GUI with ONNX model integration and camera support
    - Implemented a GUI application for smart bin classification using Tkinter.
    - Integrated ONNX model inference with image preprocessing and classification.
    - Added camera support using Picamera2 for real-time image capture.
    - Included functionality to save captured images and display classification results.
    - Configurable parameters for model path, window size, preview size, rotation, and fullscreen mode.
2026-02-26 Refactor SmartBinDisplayApp initialization to use a separate thread for model and camera setup
2026-03-12 Ledstrip code verbeterd
2026-03-12 Add serial communication for organic waste detection and update LED control
2026-03-12 Refactor LED strip variable names and remove unused code for clarity
2026-03-12 Enhance serial communication handling in InferenceGUI and add UART test script
2026-03-12 Add reset button and fullscreen toggle to InferenceGUI; update serial communication in LED strip control
2026-03-14 code aangepast zodat de PI stuurt naar de ESP
2026-03-19 Create Ultrasone sensor
2026-03-19 sensor houder
    [Sensorhouder_Ultrasonesensor_HC-SR04.stl]
2026-03-19 Add WS2812B wiring instructions, inference GUI service, and compiled inference script
    - Created a new markdown file `bedrading.md` detailing the wiring and setup for WS2812B LED strips directly connected to a Raspberry Pi, including GPIO pin assignments, power requirements, and ultras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
    - Added a new systemd service file `inference_gui.service` to manage the inference GUI application, ensuring it starts after the network and graphical environment are ready.
    - Introduced a compiled Python script for inference in the `__pycache__` directory to optimize performance.
2026-03-26 Remove unused .pyc files and update led_controller to control WS2812B strips directly from Raspberry Pi
2026-03-26 Remove unused compiled Python file for led_controller
2026-03-26 Enhance inference GUI with automatic camera initialization retries and improved error handling; update led_controller for neopixel import safety; add Pi Boot Inference Diagnoser agent for troubleshoo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
    [led_controller.py]
2026-03-26 Update sensor pin assignments for Ultrasone sensors
2026-04-23 garbagedetection & test led + ultrasoon
2026-04-30 Fusion Files
    [Dak.f3d, Deksel Volledig.f3z, Muur Klein.f3d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]
2026-04-30 objectdetectie, ledstrip, ultrasoon & pi deploy code
2026-04-30 Add link to PowerPoint presentation
2026-05-07 Enhance UltrasonicMonitor with debug capabilities and cycle tracking. Added command-line arguments for debug mode and cycle frequency. Implemented a standalone ultrasonic debug mode. Updated Inferenc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
2026-05-07 Aantal Leds aangepast
2026-05-15 aanpassing ledcount
2026-05-15 Behuizing display + extensiestuk
    [Kabels Ultrasoon.dxf, Kort_Boven.dxf, Kort_Zijkant.dxf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]
2026-05-18 Update sensor pins for 'papier' in SENSOR_MAP
2026-05-18 Aanpassing GPIO-PIN op architectuurbestand
